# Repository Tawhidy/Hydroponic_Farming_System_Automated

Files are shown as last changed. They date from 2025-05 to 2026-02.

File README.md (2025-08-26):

# Project Manual: Automated Hydroponic Farming System

# 1. Introduction

This manual provides comprehensive documentation for the Automated Hydroponic Farming System hardware project. It includes step-by-step assembly instructions, a complete bill of materials (BOM), circuit diagrams, and contributor information. This document serves as both a build guide and reference for future modifications.

## 1.1 Project Overview

The Automated Hydroponic Farming System is a self-contained solution that monitors and controls water, nutrients, and lighting for soil-free plant cultivation. This project was designed to allow anyone to grow plants indoors efficiently without requiring extensive agricultural knowledge.

## 1.2 Repository Structure

The GitHub repository is organized as follows:

- /docs - Documentation files including this manual
- /hardware - Circuit diagrams, PCB designs, and component specifications
- /firmware - Software required for operation
- /images - Photos and diagrams used throughout documentation

# 2. Bill of Materials (BOM)

Below is the complete list of components required for this project:

| **Component** | **Quantity** | **Reference** | **Description** | **Product Link** |
| --- | --- | --- | --- | --- |
| Arduino uno/nano | 2 | U1 | Microcontroller board based on ATmega328P | https://store.arduino.cc/products/arduino-nano |
| pH Sensor | 1 | S1 | Analog pH sensor with probe, 0-14 pH range | https://www.dfrobot.com/product-1025.html |
| 12V Water Pump | 4 | P1 | 12V DC submersible pump, 240L/H flow rate | https://www.adafruit.com/product/1150 |
| LED Grow Lights | 2 | L1, L2 | Full spectrum grow lights, 15W, 12V DC | https://www.sparkfun.com/products/14590 |
| mist maker | 1 | Various | Power supply, resistors, capacitors, connectors, etc. | See detailed BOM document |
| relay | 3 | | | |
| 220V - 12V power supply | 1 | | | |
| 12V - 5V buck converter | 1 | | | |
| 120mm PC fan | 2 | | | |
| glue gun | 1 | | | |
| glue stick | 8-10 | | | |

## 2.1 Tools Required

- Soldering iron, solder & solder wick
- Wire strippers
- Multimeter
- Screwdriver set
- glue gun

# 3. Circuit Diagram

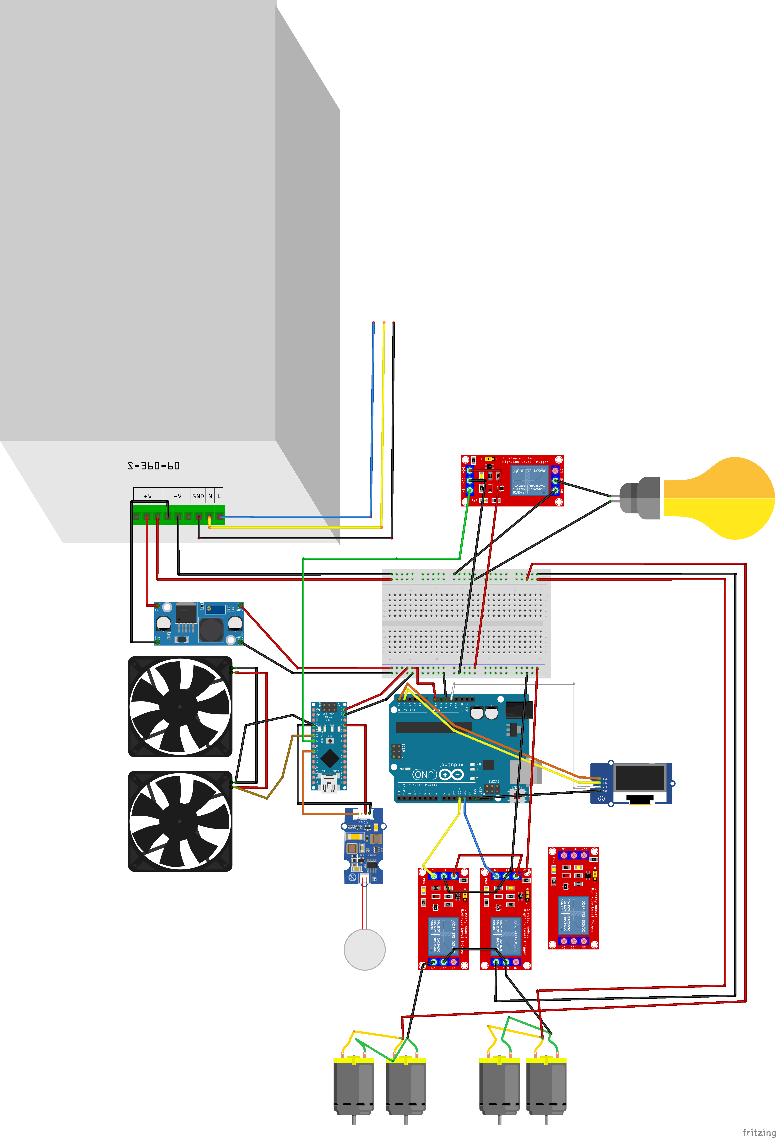
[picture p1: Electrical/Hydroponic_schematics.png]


## 3.1 Schematic Explanation

The circuit consists of the following main sections:

- **Power Supply**: 220V-12V power supply to feed into the motors using relays & 12V is then converted into 5V using the buck converter and feed power to the microcontroller and mist maker.
- **Microcontroller**: we used an Arduino UNO and one Nano. The Uno handles the display and Ph control. and the rest of the control is done by the nano ie. temperature and humidity control.
- **Sensor Circuit**: pH, temperature and humidity sensors for controlling the necessary environment for the system.
- **Output Circuit**: Relays controlling nutrient+water pumps, mist maker, LED lighting and the the fans are directly controlled by arduino.

# 4. Assembly Instructions

## 4.1 Electrical Assembly

Follow these steps to assemble the PCB:

1. Begin by soldering the smallest components first (resistors, capacitors)
2. Solder the IC sockets (do not insert the ICs yet)
3. Solder the larger components (connectors, power regulators)
4. Inspect all solder joints for quality and potential shorts
5. Clean the PCB with isopropyl alcohol to remove flux residue
6. Insert ICs into their sockets, ensuring correct orientation

## 4.2 Enclosure Assembly

If your project includes an enclosure, follow these steps:

1. Prepare the enclosure by drilling/cutting necessary openings
2. Mount the PCB using the provided standoffs and screws
3. Install any external components (switches, displays, etc.)
4. Connect any required wiring between the PCB and external components
5. Secure the enclosure with the provided fasteners

# 5. Testing and Verification

After assembly, follow these steps to verify correct operation:

1. Visual inspection of all connections
2. Continuity testing of power rails
3. Initial power-up test (without connected peripherals)
4. Functional testing of each subsystem
5. Integration testing of the complete system

## 5.1 Troubleshooting Guide

If you encounter issues, refer to this troubleshooting guide:

| **Symptom** | **Possible Cause** | **Solution** |
| --- | --- | --- |
| No power | Incorrect power connections | Check power supply connections and polarity |
| Erratic behavior | Cold solder joints | Inspect and reflow suspicious solder joints |
| Sensor readings incorrect | Improper calibration | Recalibrate sensors using known reference values |

# 6. Firmware Installation

To install the firmware:

1. Download the latest firmware from the /firmware directory
2. Connect the Arduino Nano to your computer via USB
3. Use the Arduino IDE to flash the firmware
4. Verify successful firmware installation by checking the serial monitor output

# 7. Usage Instructions

Once assembled and programmed, your hydroponic system will automatically monitor and adjust growing conditions. Use the companion smartphone app to check status and customize settings for your specific plants.

# 8. Contributors

This project was made possible by the contributions of the following individuals:

## 8.1 Core Team

- **Tawhid Alam** - Project Lead
    - GitHub: [https://github.com/tawhidalam](https://github.com/tawhidalam)
    - Email: [email address]
- **[Contributor Name]** - [Role]
    - GitHub: [GitHub profile link]
    - Website: [Personal website if available]
- **[Contributor Name]** - [Role]
    - GitHub: [GitHub profile link]
    - LinkedIn: [LinkedIn profile link]

## 8.2 Contributors

- **[Contributor Name]** - [Contribution]
- **[Contributor Name]** - [Contribution]

# 9. License Information

This project is licensed under the MIT License. See the LICENSE file in the repository for full details.

# 10. Appendix

## 10.1 Additional Resources

- Datasheets for key components
- Reference designs
- Additional documentation

## 10.2 Version History

| **Version** | **Date** | **Changes** |
| --- | --- | --- |
| 1.0 | 2025-08-05 | Initial release |

The appendix also includes detailed visual aids (component photos, assembly steps)

[^1]:

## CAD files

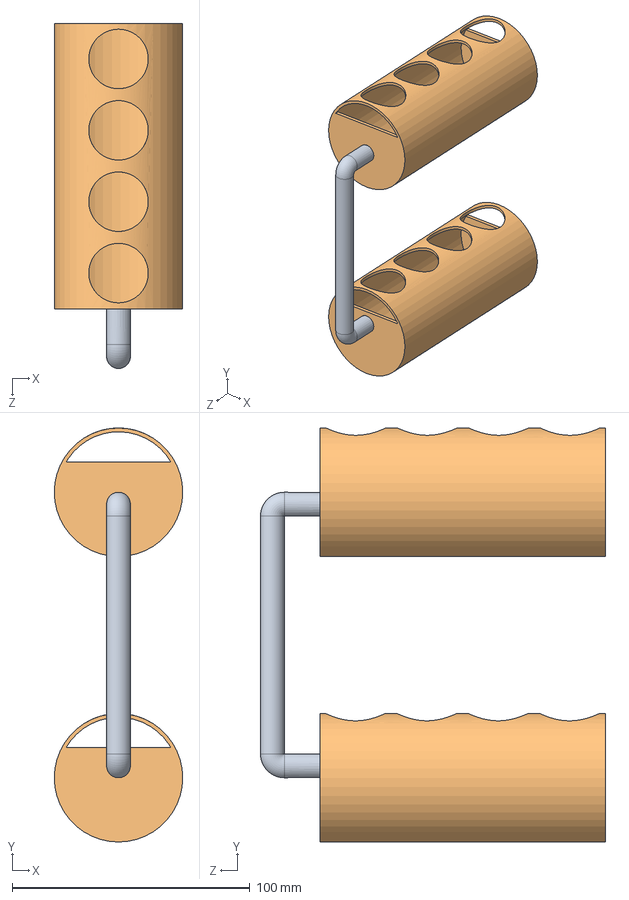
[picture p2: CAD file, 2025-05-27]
Mechanical/Demo/Assem1.SLDASM
54.0 x 174.0 x 145.0 mm
Pvc cutout for plant x 2
connecting pipe

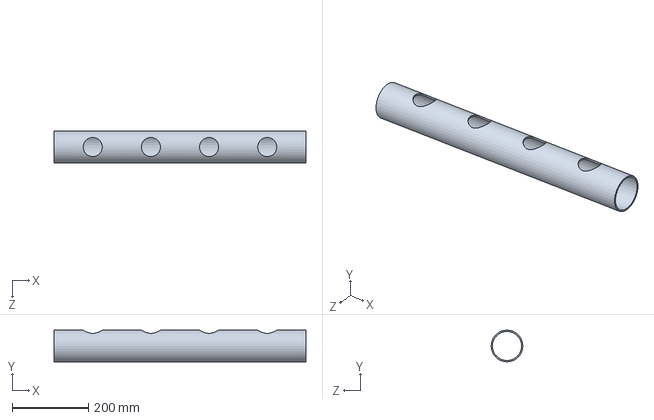
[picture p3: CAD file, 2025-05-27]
Mechanical/final/main_pipe.SLDPRT
660.4 x 83.0 x 83.0 mm

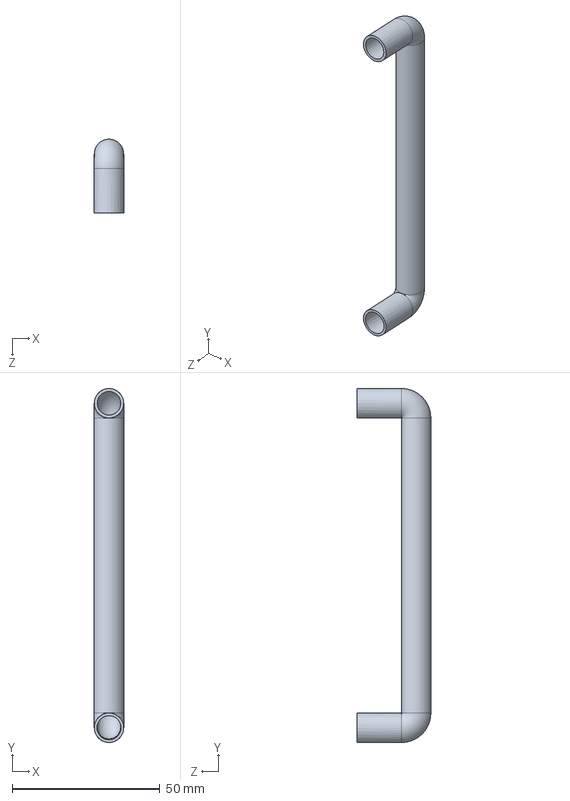
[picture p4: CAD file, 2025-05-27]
Mechanical/Demo/connecting pipe.SLDPRT
10.0 x 120.0 x 25.0 mm

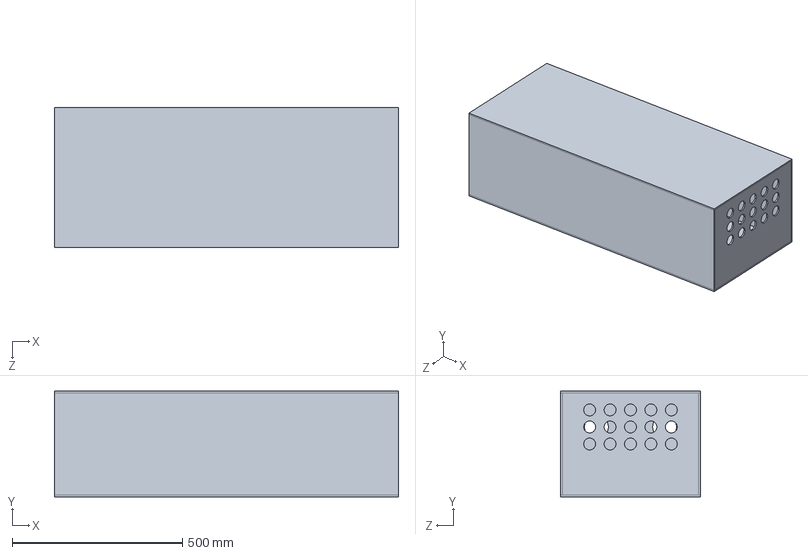
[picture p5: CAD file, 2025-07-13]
Mechanical/final/Box-acrylic.SLDPRT
1010.0 x 310.0 x 410.0 mm

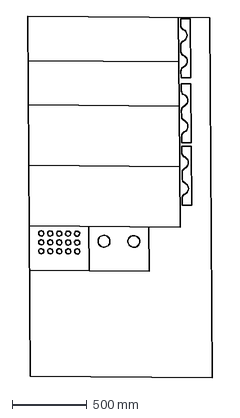
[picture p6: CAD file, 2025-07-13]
Mechanical/final/Dxf Files/4ft_8ft_Acrylic_sheet layout.DXF
1233.4 x 2410.7 mm

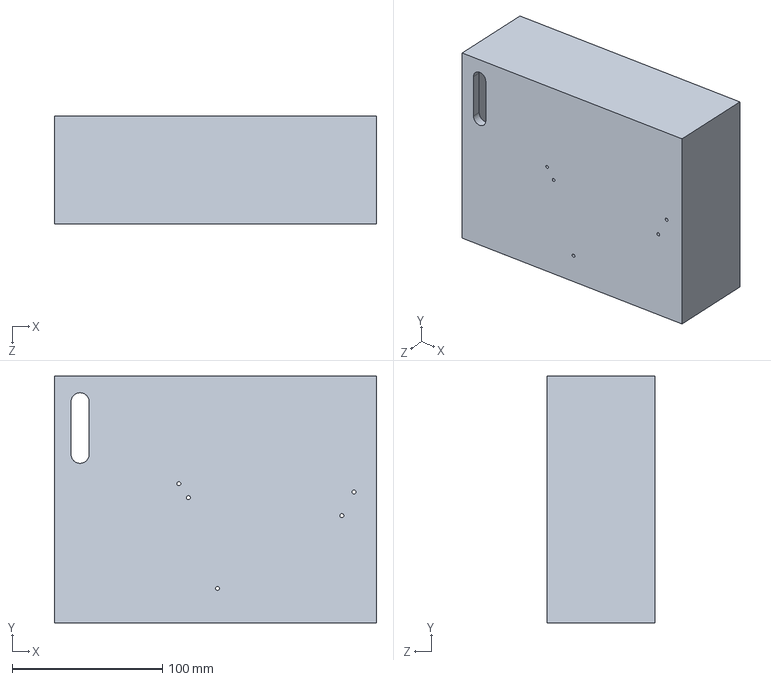
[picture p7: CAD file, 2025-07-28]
Mechanical/final/Electrical box/box.SLDPRT
214.0 x 164.0 x 72.0 mm

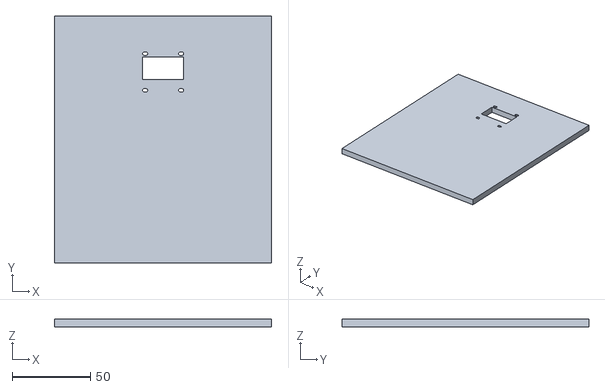
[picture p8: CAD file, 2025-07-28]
Mechanical/final/Electrical box/STL/front_panel_V2.STL
139.0 x 158.0 x 5.00

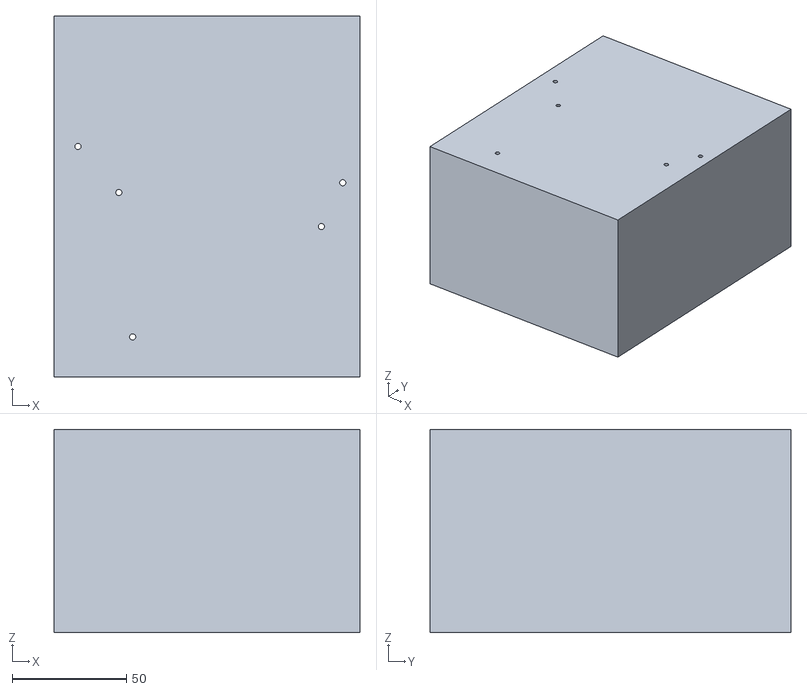
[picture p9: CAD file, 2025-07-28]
Mechanical/final/Electrical box/STL/box_v2.STL
134.0 x 158.0 x 89.0

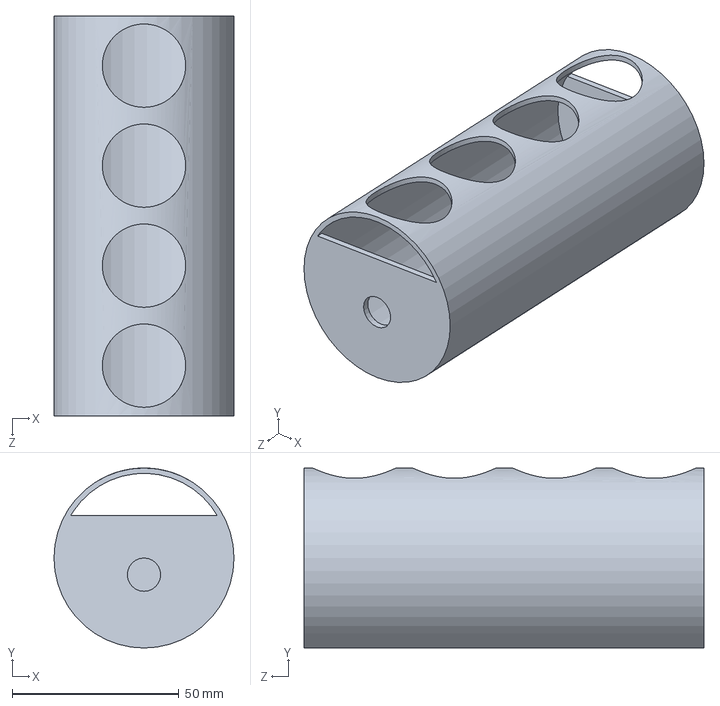
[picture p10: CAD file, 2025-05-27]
Mechanical/Demo/Pvc cutout for plant.SLDPRT
54.0 x 54.0 x 120.0 mm

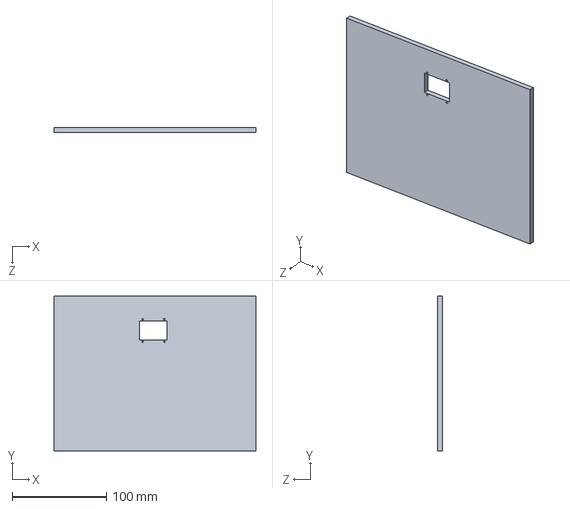
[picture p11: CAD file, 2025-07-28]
Mechanical/final/Electrical box/front panel.SLDPRT
214.0 x 164.0 x 5.00 mm

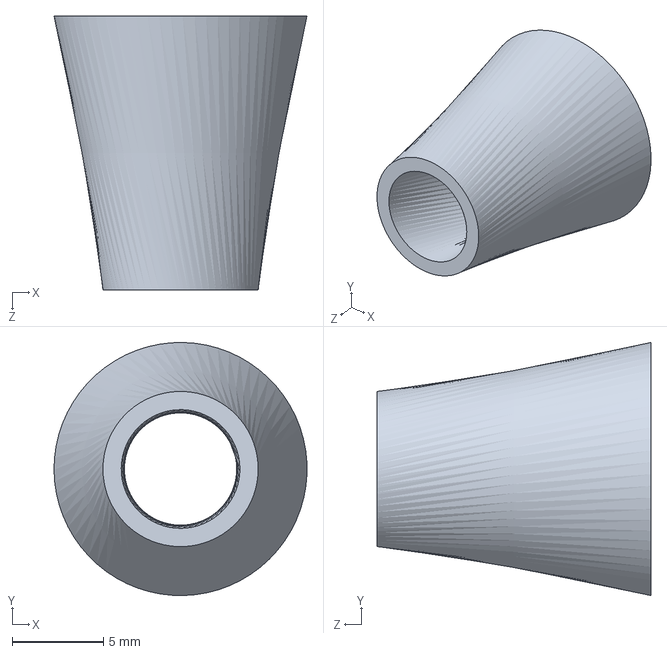
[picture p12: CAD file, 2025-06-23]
Mechanical/final/tapered_pipe_holder(3dp).SLDPRT
13.9 x 13.9 x 15.0 mm

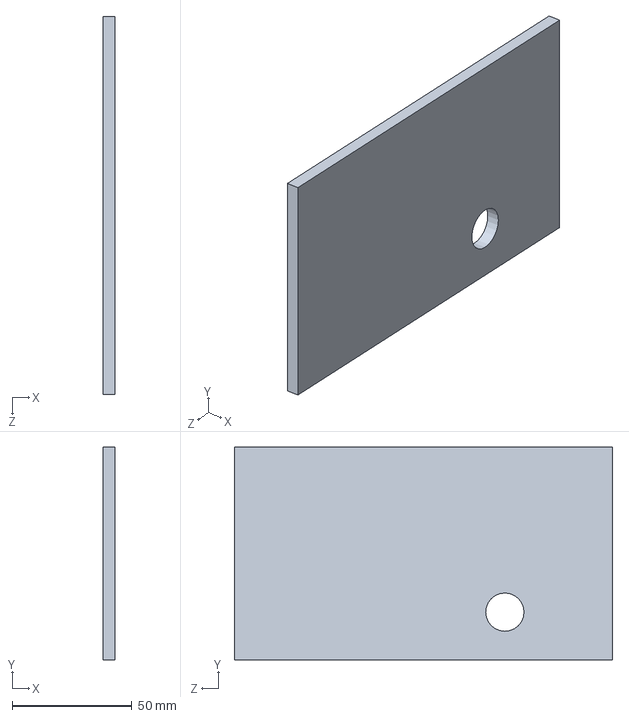
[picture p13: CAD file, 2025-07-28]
Mechanical/final/Electrical box/side_panel.SLDPRT
5.00 x 89.0 x 158.0 mm

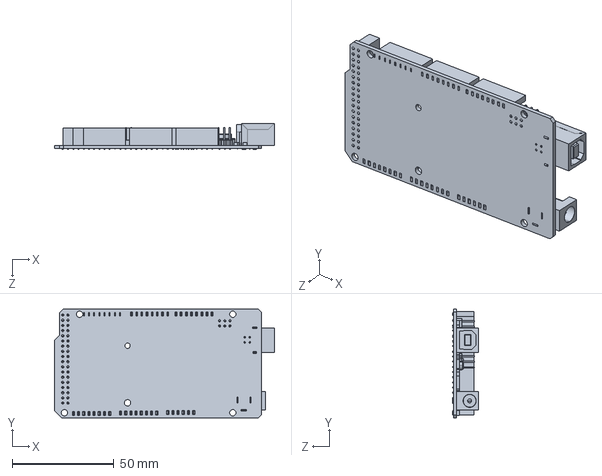
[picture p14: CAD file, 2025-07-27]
Mechanical/final/Electrical box/ArduinoMega_STEP_AP203.STEP
107.9 x 53.4 x 13.0 mm

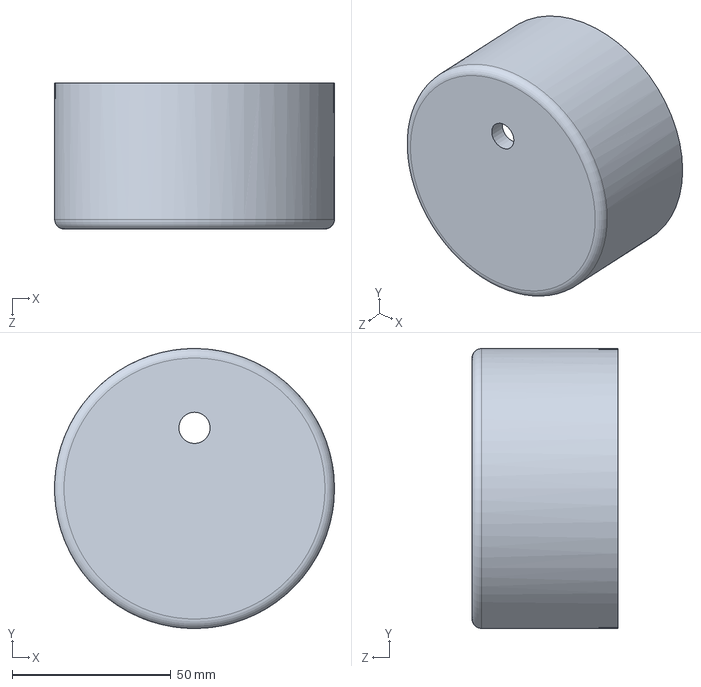
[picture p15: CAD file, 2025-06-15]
Mechanical/final/end_cap_w-holes(3dp).SLDPRT
88.2 x 88.2 x 46.0 mm

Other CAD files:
Mechanical/final/Electrical box/Enclousure.SLDASM
Mechanical/final/main_assembly.SLDASM
Mechanical/final/pipe_w-connector.SLDASM
Mechanical/final/Electrical box/Pantalla OLED 0.96'' 128x64.stp
Mechanical/final/3in-1.5in_socket.SLDPRT
Mechanical/final/Bend_pipe_L.SLDPRT
Mechanical/final/Electrical box/PSU.SLDPRT
Mechanical/final/Electrical box/STL/box.STL
Mechanical/final/Electrical box/STL/front panel.STL
Mechanical/final/Electrical box/STL/side_panel.STL
Mechanical/final/connecting_pipe_1.SLDPRT
Mechanical/final/connecting_pipe_2.SLDPRT
Mechanical/final/end_cap_w-holes-outlet(3dp).SLDPRT
Mechanical/final/stl files/end_cap_w-holes(3dp).STL
Mechanical/final/stl files/end_cap_w-holes-outlet(3dp).STL
Mechanical/final/stl files/tapered_pipe_holder(3dp).STL

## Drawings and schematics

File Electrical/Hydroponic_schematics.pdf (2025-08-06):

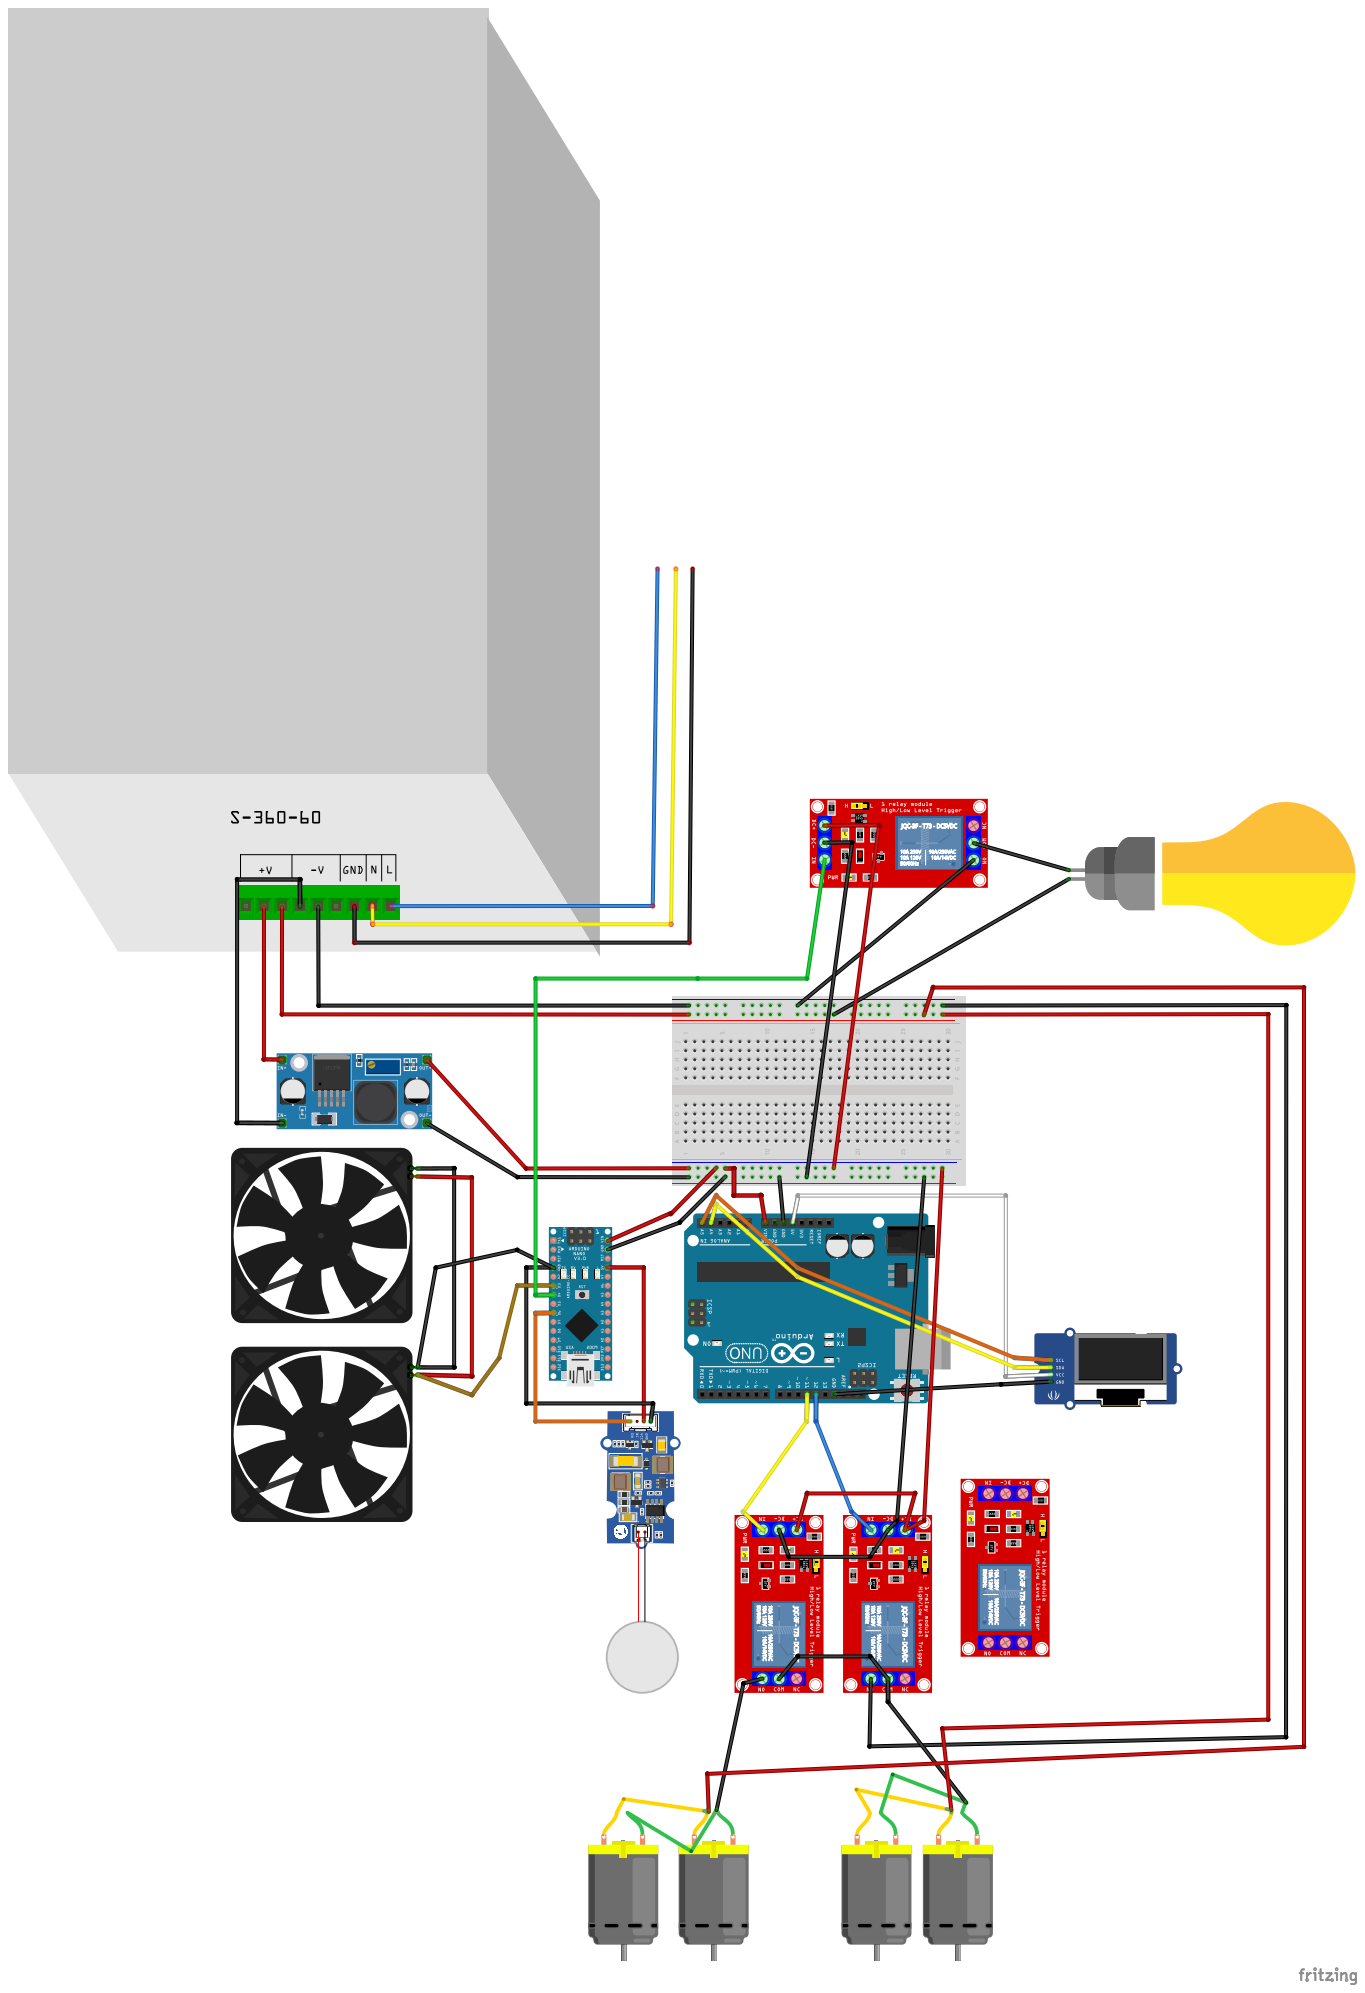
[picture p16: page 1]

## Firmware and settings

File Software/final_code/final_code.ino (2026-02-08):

#include <Wire.h>
#include <Adafruit_GFX.h>
#include <Adafruit_SSD1306.h>
#include <DHT.h>

// OLED display dimensions
#define SCREEN_WIDTH 128
#define SCREEN_HEIGHT 64
#define OLED_RESET    -1
Adafruit_SSD1306 display(SCREEN_WIDTH, SCREEN_HEIGHT, &Wire, OLED_RESET);

// DHT sensor setup (digital pin 2)
#define DHTPIN 6
#define DHTTYPE DHT11
DHT dht(DHTPIN, DHTTYPE);

// Relay pins for environmental control
#define FAN_RELAY_PIN        5   // Relay for fan
#define LIGHT_RELAY_PIN      4   // Relay for light
#define HUMIDIFIER_RELAY_PIN 3   // Relay for humidifier

// Relay logic levels (some relays may be active HIGH or active LOW)
const int FAN_ACTIVE_LEVEL        = HIGH;
const int FAN_INACTIVE_LEVEL      = LOW;
const int LIGHT_ACTIVE_LEVEL      = HIGH;
const int LIGHT_INACTIVE_LEVEL    = LOW;
const int HUMIDIFIER_ACTIVE_LEVEL   = LOW;   // Humidifier is active LOW
const int HUMIDIFIER_INACTIVE_LEVEL = HIGH;

// Thresholds for control
float FAN_TEMP_THRESHOLD    = 35.0;  // °C, if ≥ this, turn on fan
float LIGHT_TEMP_THRESHOLD  = 30.0;  // °C, if ≤ this, turn on light
float HUM_HUMID_THRESHOLD   = 60.0;  // %, if < this, turn on humidifier

// pH sensor and tank relay pins
const int pHAnalogPin      = A0;  // pH sensor analog input (A0)
const int primaryRelayPin   = 12; // Relay for Primary tank (digital pin 12)
const int secondaryRelayPin = 11; // Relay for Secondary tank (digital pin 11)

void setup() {
  Serial.begin(9600); 
  // Initialize DHT sensor
  dht.begin();
  // Initialize relay output pins
  pinMode(FAN_RELAY_PIN, OUTPUT);
  pinMode(LIGHT_RELAY_PIN, OUTPUT);
  pinMode(HUMIDIFIER_RELAY_PIN, OUTPUT);
  pinMode(primaryRelayPin, OUTPUT);
  pinMode(secondaryRelayPin, OUTPUT);
  // Set relays to safe default states: all OFF except Primary ON
  digitalWrite(FAN_RELAY_PIN,        FAN_INACTIVE_LEVEL);
  digitalWrite(LIGHT_RELAY_PIN,      LIGHT_INACTIVE_LEVEL);
  digitalWrite(HUMIDIFIER_RELAY_PIN, HUMIDIFIER_INACTIVE_LEVEL);
  digitalWrite(primaryRelayPin, HIGH);  // Primary tank ON
  digitalWrite(secondaryRelayPin, LOW); // Secondary tank OFF

  // Initialize I2C and OLED display
  Wire.begin(); // SDA/SCL on Mega (20/21):contentReference[oaicite:3]{index=3}
  if (!display.begin(SSD1306_SWITCHCAPVCC, 0x3C)) { 
    Serial.println("SSD1306 allocation failed");
    for(;;); // Hang if display init fails
  }
  display.clearDisplay();
  display.setTextSize(1);
  display.setTextColor(SSD1306_WHITE);
  Serial.println("Combined environment and pH control starting...");
}

// Reads DHT sensor (with a 2s delay) and returns values via reference parameters.
// (Uses dht.readHumidity() and dht.readTemperature() as documented:contentReference[oaicite:4]{index=4}.)
void readTempHumidity(float &temp, float &hum) {
  delay(2000); // DHT11 timing requirement (2000 ms) 
  hum = dht.readHumidity();
  temp = dht.readTemperature();
  // If reading failed, keep temp/hum at previous values (or NaN); print error
  if (isnan(hum) || isnan(temp)) {
    Serial.println("Failed to read from DHT sensor!");
    return;
  }
  Serial.print("Temp: "); Serial.print(temp);
  Serial.print(" C, Hum: "); Serial.print(hum); Serial.println(" %");
}

// Applies control logic for fan/light/humidifier based on temp/hum.
// Exclusive fan/light: if hot, fan ON (light off); if cold, light ON (fan off); else both off.
// Humidifier: ON if humidity is below threshold.
// (Implements logic from original temp_humidity_control sketch.)
void controlEnvironment(float temp, float hum) {
  bool fanOn = false, lightOn = false;
  if (temp >= FAN_TEMP_THRESHOLD) {
    fanOn = true; 
    lightOn = false;
  }
  else if (temp <= LIGHT_TEMP_THRESHOLD) {
    lightOn = true;
    fanOn = false;
  }
  else {
    fanOn = false;
    lightOn = false;
  }
  bool humidifierOn = (hum < HUM_HUMID_THRESHOLD);

  digitalWrite(FAN_RELAY_PIN,        fanOn        ? FAN_ACTIVE_LEVEL        : FAN_INACTIVE_LEVEL);
  digitalWrite(LIGHT_RELAY_PIN,      lightOn      ? LIGHT_ACTIVE_LEVEL      : LIGHT_INACTIVE_LEVEL);
  digitalWrite(HUMIDIFIER_RELAY_PIN, humidifierOn ? HUMIDIFIER_ACTIVE_LEVEL : HUMIDIFIER_INACTIVE_LEVEL);

  Serial.print("Fan: "); Serial.print(fanOn ? "ON" : "OFF");
  Serial.print(" | Light: "); Serial.print(lightOn ? "ON" : "OFF");
  Serial.print(" | Humidifier: "); Serial.println(humidifierOn ? "ON" : "OFF");
}

// Samples the pH sensor 50 times (100 ms apart) to compute an average pH.
// Converts the analog reading to voltage and then to pH using the calibration formula.
float readAveragePH() {
  float sumPH = 0.0;
  for (int i = 0; i < 50; i++) {
    int raw = analogRead(pHAnalogPin);
    float voltage = raw * (5.0 / 1023.0); // ADC 10-bit (0–1023) over 0–5V
    float pHValue = 7.0 - (7.0/2.5) * (voltage - 2.5); // calibration: 2.5V→pH7
    sumPH += pHValue;
    delay(100);
  }
  float avgPH = sumPH / 50.0;
  Serial.print("Average pH: ");
  Serial.println(avgPH);
  return avgPH;
}

// Controls tank relays based on averaged pH.
// If pH is outside [6.0, 8.0], switch to Secondary tank; otherwise use Primary.
void controlTanks(float avgPH) {
  if (avgPH < 6.0 || avgPH > 8.0) {
    // pH out of safe range: Secondary ON
    digitalWrite(primaryRelayPin, LOW);   // Primary OFF
    digitalWrite(secondaryRelayPin, HIGH); // Secondary ON
  } else {
    // pH in range: Primary ON
    digitalWrite(secondaryRelayPin, LOW);   // Secondary OFF
    digitalWrite(primaryRelayPin, HIGH);   // Primary ON
  }
}

// Updates the OLED display with temperature, humidity, and pH.
void updateDisplay(float temp, float hum, float avgPH) {
  display.clearDisplay();
  display.setTextSize(1);
  display.setCursor(0, 0);
  display.print("Temp: "); display.print(temp); display.println(" C");
  display.print("Hum:  "); display.print(hum);  display.println(" %");
  display.print("pH:   "); display.print(avgPH);
  display.display();
}

void loop() {
  // 1. Read and control pH system
  float avgPH = readAveragePH();
  controlTanks(avgPH);

  // 2. Read and control temperature/humidity system
  float temperature = NAN, humidity = NAN;
  readTempHumidity(temperature, humidity);
  if (!isnan(temperature) && !isnan(humidity)) {
    controlEnvironment(temperature, humidity);
  }

  // 3. Update OLED display
  updateDisplay(temperature, humidity, avgPH);

  // The loop naturally repeats (~7 seconds due to DHT & pH delays).
}

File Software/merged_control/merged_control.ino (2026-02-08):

#include <Wire.h>
#include <Adafruit_GFX.h>
#include <Adafruit_SSD1306.h>
#include <DHT.h>

#define SCREEN_WIDTH 128
#define SCREEN_HEIGHT 64
#define OLED_RESET -1
Adafruit_SSD1306 display(SCREEN_WIDTH, SCREEN_HEIGHT, &Wire, OLED_RESET);

#define DHTPIN 2
#define DHTTYPE DHT11
DHT dht(DHTPIN, DHTTYPE);

// Relay pins
#define FAN_RELAY_PIN        5
#define LIGHT_RELAY_PIN      4
#define HUMIDIFIER_RELAY_PIN 3
#define FAN_ACTIVE_LEVEL        HIGH
#define FAN_INACTIVE_LEVEL      LOW
#define LIGHT_ACTIVE_LEVEL      HIGH
#define LIGHT_INACTIVE_LEVEL    LOW
#define HUMIDIFIER_ACTIVE_LEVEL   LOW
#define HUMIDIFIER_INACTIVE_LEVEL HIGH

float FAN_TEMP_THRESHOLD    = 35.0;
float LIGHT_TEMP_THRESHOLD  = 28.0;
float HUM_HUMID_THRESHOLD   = 70.0;

const int pHAnalogPin      = A0;
const int primaryRelayPin   = 12;
const int secondaryRelayPin = 11;

const int buzzerPin = 14;
const unsigned long TRANSITION_BEEP_MS     = 2000UL;
const unsigned long PERIODIC_BEEP_INTERVAL = 5000UL;
const unsigned long PERIODIC_BEEP_DURATION = 200UL;
const unsigned int  BUZZER_FREQ = 1000;

bool secondaryActivePrev = false;
bool inTransitionBeep = false;
unsigned long transitionStartMillis = 0;
bool periodicActive = false;
unsigned long periodicLastBeepMillis = 0;
bool periodicBeepOn = false;
unsigned long periodicBeepStartMillis = 0;

// ---- pH averaging variables ----
unsigned long lastUpdate = 0;
float sumPH = 0;
int countPH = 0;

void setup() {
  Serial.begin(9600);

  if (!display.begin(SSD1306_SWITCHCAPVCC, 0x3C)) {
    Serial.println(F("SSD1306 allocation failed"));
    for(;;);
  }
  display.clearDisplay();
  display.setTextSize(1);
  display.setTextColor(SSD1306_WHITE);

  dht.begin();

  pinMode(FAN_RELAY_PIN, OUTPUT);
  pinMode(LIGHT_RELAY_PIN, OUTPUT);
  pinMode(HUMIDIFIER_RELAY_PIN, OUTPUT);
  pinMode(primaryRelayPin, OUTPUT);
  pinMode(secondaryRelayPin, OUTPUT);
  pinMode(buzzerPin, OUTPUT);
  digitalWrite(buzzerPin, LOW);

  digitalWrite(FAN_RELAY_PIN, FAN_INACTIVE_LEVEL);
  digitalWrite(LIGHT_RELAY_PIN, LIGHT_INACTIVE_LEVEL);
  digitalWrite(HUMIDIFIER_RELAY_PIN, HUMIDIFIER_INACTIVE_LEVEL);
  digitalWrite(primaryRelayPin, HIGH);
  digitalWrite(secondaryRelayPin, LOW);

  Serial.println("System start");
}

bool controlTanks(float avgPH) {
  bool secondaryActive = false;
  if (avgPH < 6.0 || avgPH > 8.0) {
    digitalWrite(primaryRelayPin, LOW);
    digitalWrite(secondaryRelayPin, HIGH);
    secondaryActive = true;
  } else {
    digitalWrite(secondaryRelayPin, LOW);
    digitalWrite(primaryRelayPin, HIGH);
    secondaryActive = false;
  }
  return secondaryActive;
}

void controlEnvironment(float temp, float hum) {
  bool fanOn = false, lightOn = false;
  if (temp >= FAN_TEMP_THRESHOLD) {
    fanOn = true; lightOn = false;
  } else if (temp <= LIGHT_TEMP_THRESHOLD) {
    fanOn = false; lightOn = true;
  }
  bool humidifierOn = (hum < HUM_HUMID_THRESHOLD);

  digitalWrite(FAN_RELAY_PIN, fanOn ? FAN_ACTIVE_LEVEL : FAN_INACTIVE_LEVEL);
  digitalWrite(LIGHT_RELAY_PIN, lightOn ? LIGHT_ACTIVE_LEVEL : LIGHT_INACTIVE_LEVEL);
  digitalWrite(HUMIDIFIER_RELAY_PIN, humidifierOn ? HUMIDIFIER_ACTIVE_LEVEL : HUMIDIFIER_INACTIVE_LEVEL);
}

void updateDisplay(float temp, float hum, float avgPH) {
  display.clearDisplay();
  display.setTextColor(SSD1306_WHITE);

  display.setTextSize(2);
  display.setCursor(0, 0);
  display.print("T:");
  if (!isnan(temp)) display.print(temp, 1);
  else display.print("--");
  display.print("C");

  display.setCursor(0, 18);
  display.print("H:");
  if (!isnan(hum)) display.print(hum, 0);
  else display.print("--");
  display.print("%");

  display.setCursor(0, 36);
  display.print("pH:");
  display.print(avgPH, 2);

  display.setTextSize(1);
  display.setCursor(0, 54);
  bool fanOn = (digitalRead(FAN_RELAY_PIN) == FAN_ACTIVE_LEVEL);
  bool lightOn = (digitalRead(LIGHT_RELAY_PIN) == LIGHT_ACTIVE_LEVEL);
  bool humidOn = (digitalRead(HUMIDIFIER_RELAY_PIN) == HUMIDIFIER_ACTIVE_LEVEL);
  display.print("Fan:");   display.print(fanOn  ? "ON " : "OFF ");
  display.print("Light:"); display.print(lightOn? "ON " : "OFF ");
  display.print("Hum:");   display.print(humidOn? "ON"  : "OFF");

  display.display();
}

void handleBuzzerState(bool secondaryActive) {
  unsigned long now = millis();

  if (secondaryActive != secondaryActivePrev) {
    inTransitionBeep = true;
    transitionStartMillis = now;
    periodicActive = false;
    periodicBeepOn = false;
    tone(buzzerPin, BUZZER_FREQ);
  }

  if (inTransitionBeep) {
    if (now - transitionStartMillis >= TRANSITION_BEEP_MS) {
      noTone(buzzerPin);
      inTransitionBeep = false;
      if (secondaryActive) {
        periodicActive = true;
        periodicLastBeepMillis = now;
      }
    }
    secondaryActivePrev = secondaryActive;
    return;
  }

  if (periodicActive && secondaryActive) {
    if (!periodicBeepOn && (now - periodicLastBeepMillis >= PERIODIC_BEEP_INTERVAL)) {
      tone(buzzerPin, BUZZER_FREQ);
      periodicBeepOn = true;
      periodicBeepStartMillis = now;
    }
    if (periodicBeepOn && (now - periodicBeepStartMillis >= PERIODIC_BEEP_DURATION)) {
      noTone(buzzerPin);
      periodicBeepOn = false;
      periodicLastBeepMillis = now;
    }
  } else {
    periodicActive = false;
    if (periodicBeepOn) {
      noTone(buzzerPin);
      periodicBeepOn = false;
    }
  }

  if (!inTransitionBeep) {
    secondaryActivePrev = secondaryActive;
  }
}

void loop() {
  // accumulate pH samples quickly (no big delays)
  int raw = analogRead(pHAnalogPin);
  float voltage = raw * (5.0 / 1023.0);
  float pHValue = 7.0 - (7.0/2.5) * (voltage - 2.5);
  sumPH += pHValue;
  countPH++;

  if (millis() - lastUpdate >= 2000) {
    float avgPH = sumPH / countPH;

    bool secondaryActive = controlTanks(avgPH);
    handleBuzzerState(secondaryActive);

    float humidity = dht.readHumidity();
    float temperature = dht.readTemperature();
    if (!isnan(temperature) && !isnan(humidity)) {
      controlEnvironment(temperature, humidity);
    }

    updateDisplay(temperature, humidity, avgPH);

    sumPH = 0;
    countPH = 0;
    lastUpdate = millis();
  }
}

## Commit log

2025-05-27 cap ID reduced to 82.2mm
    [end_cap_w-holes(3dp).STL, end_cap_w-holes-outlet(3dp).STL]
2025-06-15 3dp tolerance added
    [end_cap_w-holes(3dp).SLDPRT, end_cap_w-holes-outlet(3dp).SLDPRT]
2025-06-15 ph calibrated
2025-06-23 box update
    [Box-acrylic.SLDPRT, main_assembly.SLDASM, pipe_w-connector.SLDASM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]
2025-06-24 acrylic box defined w/ pipe mount
    [Box-acrylic.SLDPRT, main_assembly.SLDASM]
2025-07-05 dxf files added
    [1xExhause_panel_400x300.DXF, 1xIntake_side_400x300.DXF, 2xBottom_1010x410.DXF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]
2025-07-13 Dxf files and code added
    [1xExhause_panel_400x300.DXF, 1xIntake_side_400x300.DXF, 2xBottom_1010x410.DXF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]
2025-07-27 ecelctrical enclousure cad submission
    [ArduinoMega_STEP_AP203.STEP, Enclousure.SLDASM, PSU.SLDPRT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]
2025-07-28 enclosure updated
    [Enclousure.SLDASM, box.SLDPRT, box_v2.STL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]
2025-08-06 electrical schematics uploaded
    [Hydroponic_schematics.fz, Hydroponic_schematics.fzz]
2025-08-06 updated circuit schematics
2025-08-26 Add temp/humidity control and toggle button sketches
    Introduces Arduino sketches for environmental control using DHT11 sensor and relay outputs, and a toggle button example with debounce logic. The main control sketch manages fan, light, and humidifier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
